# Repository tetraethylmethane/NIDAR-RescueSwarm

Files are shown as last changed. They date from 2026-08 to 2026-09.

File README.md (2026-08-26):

<h1 align="center">NIDAR RescueSwarm</h1>

<p align="center">
  Three autonomous drones that search a flood zone, find survivors, geotag them,<br>
  and drop medical kits — with no network, no pilot, and one operator who only presses start.
</p>

<p align="center">
  <b>NIDAR 2026–27 · Track 1 · Mission 1</b><br>
  <sub>MeitY · Drone Federation of India · SwaYaan</sub>
</p>

<p align="center">
  
  
  
  
</p>

---

## 1. Status

**Phase 0/1.** Sized end to end, requirements baselined against the rulebook, and the ground station runs as a system against three real ArduCopter SITL autopilots.

**What exists:** coverage planner, geotag geometry and its error model, ArduPilot parameter sets, safety-link protocol, ground station. All tested — 129 + 17 + 67 tests, 13 committed model outputs.

**What does not:** the aircraft, and the detector. There is **no camera anywhere in the loop**; survivors have only ever come from a simulator. Nothing has flown on hardware.

<p align="center">
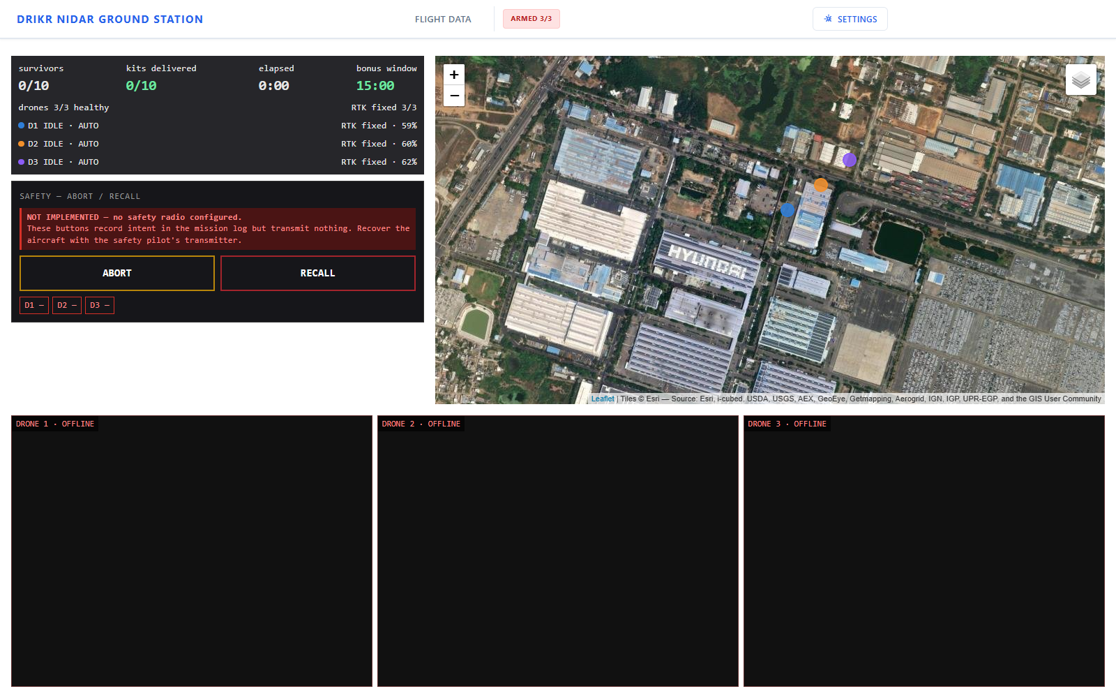
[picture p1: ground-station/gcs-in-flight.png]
Ground station mid-mission: three drones in AUTO at 40 m over offline satellite imagery
  
  <br>
  <sub>Three real autopilots flying the coverage planner's output in AUTO, in 6 m/s wind, over locally cached imagery. Every number came from an autopilot.<br>
  ▶ <a href="ground-station/mission-flight.mp4">mission-flight.mp4</a> · <a href="ground-station/README.md">ground-station/README.md</a></sub>
</p>

### Next actions

| # | Action | When | Why first |
|:--|:--|:--|:--|
| 1 | [Send the organiser questions](docs/requirements/organiser-questions.md) — drafted | This week | External latency; nothing else here has any |
| 2 | Start collecting recall data | P1 | The long pole. 250 points, irreducible calendar cost |
| 3 | Bench the cold-boot timing | P1 | The only constraint under 20 % margin, still modelled |

Registration Aug 2026 · reviews Oct and Dec · **finals Jan 2027**. About 21 weeks, but monsoon and exams cut the **flight-test window to ~8 weeks**. See the [development plan](docs/development-plan.md).

---

## 2. Design point

Outputs of a closed model in [`tools/sizing-model/`](tools/sizing-model/), reconciled with the BOM to ~2 %.

| Aircraft | | Mission | |
|:--|:--|:--|:--|
| Configuration | Quadrotor · 18 in CF folding props | Design mission | **7.7 min** of 30 |
| Battery | 6S3P 21700 · 18 cells · 292 Wh | Search | 60 m AGL at 8 m/s |
| MTOW | 6.36 kg *(model)* · 6.23 kg *(BOM)* | Sweep | 93 s/drone, 10 ha over 3 |
| **Fleet** | **19.1 kg** of 25 kg — 24 % margin | GSD | 1.82 cm/px — a person is ~93 px |
| Hover | 913 W · 9.7 kg/m² disk loading | Link | ≥13 dB at 600 m · 2.5 Mbps |
| Endurance | 15.3 min — **≈2.0× the mission** ⚠ | Geotag target | CEP50 ≤ 0.75 m with RTK |
| Thrust-to-weight | 2.0 static · hover at 50 % | Delivery target | ≥60 % within 2 m, ≥30 % within 1 m |

> ⚠ **The reserve is spent.** The 300 g parachute (SYS-41) takes endurance to ≈2.0× against a self-imposed ≥2.0× policy. Any further mass growth breaks it. See [`bom_reconcile.py`](tools/sizing-model/bom_reconcile.py).
>
> **Under review:** 40 m beats 60 m — 140 px on a person instead of 93, for 2.5 min of a 15 min allowance. Pending recall measurement in P7.

---

## 3. Proof

Three ArduCopter SITL instances, the real `rescueswarm-drone{1,2,3}.parm`, the real planned missions. Every number below came off MAVLink. Telemetry is committed in [`simulations/recordings/`](simulations/recordings/); the figures redraw from it.

### 3.1 The battery failsafe brings them home

`BATT_FS_LOW_ACT = 2` had been reviewed and unit-tested for weeks, and **no simulation ever loaded the file** — every SITL script used stock defaults, where the value is `0` and a low battery does nothing at all. Now proven end to end: RTL fires at **10 809 mAh of a 10 800 mAh trip**, on all three aircraft, within two seconds of each other.

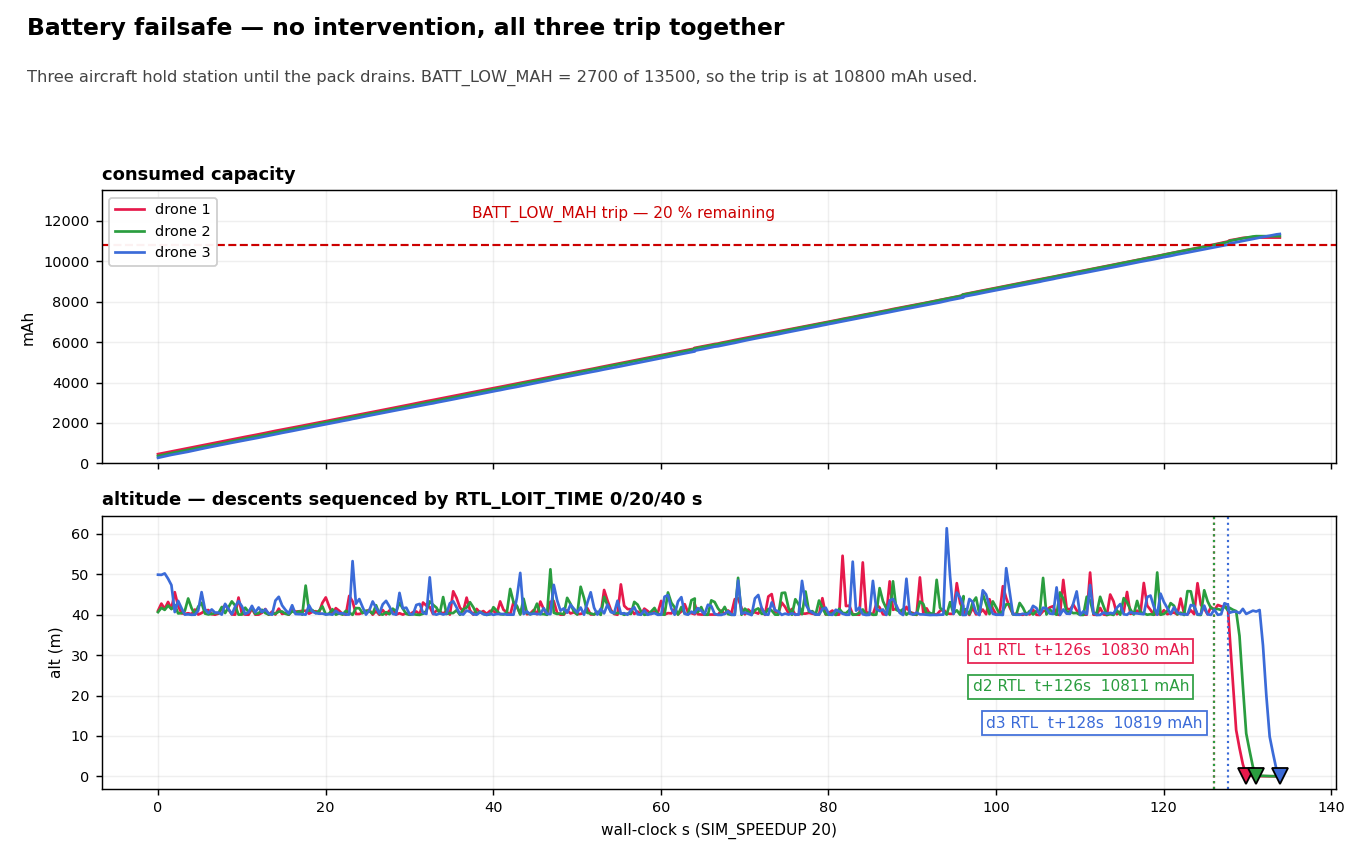
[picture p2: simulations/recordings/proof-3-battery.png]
Battery failsafe


### 3.2 They no longer collide

Three defects, none visible in review, all found by running the real artifact:

- **Launches were simultaneous.** Three aircraft leaving slots 1.22 m apart measured 1.3 m from each other at 2–3 m altitude. Now `NAV_DELAY` 0/15/30 s in the mission file.
- **Two of three swept the wrong way round**, finishing 516 m and 540 m from the pad on the lowest state of charge of the flight, because sweep direction keyed on drone index. Now all three finish inside 130 m, same path length.
- **They landed on top of each other.** See §4.

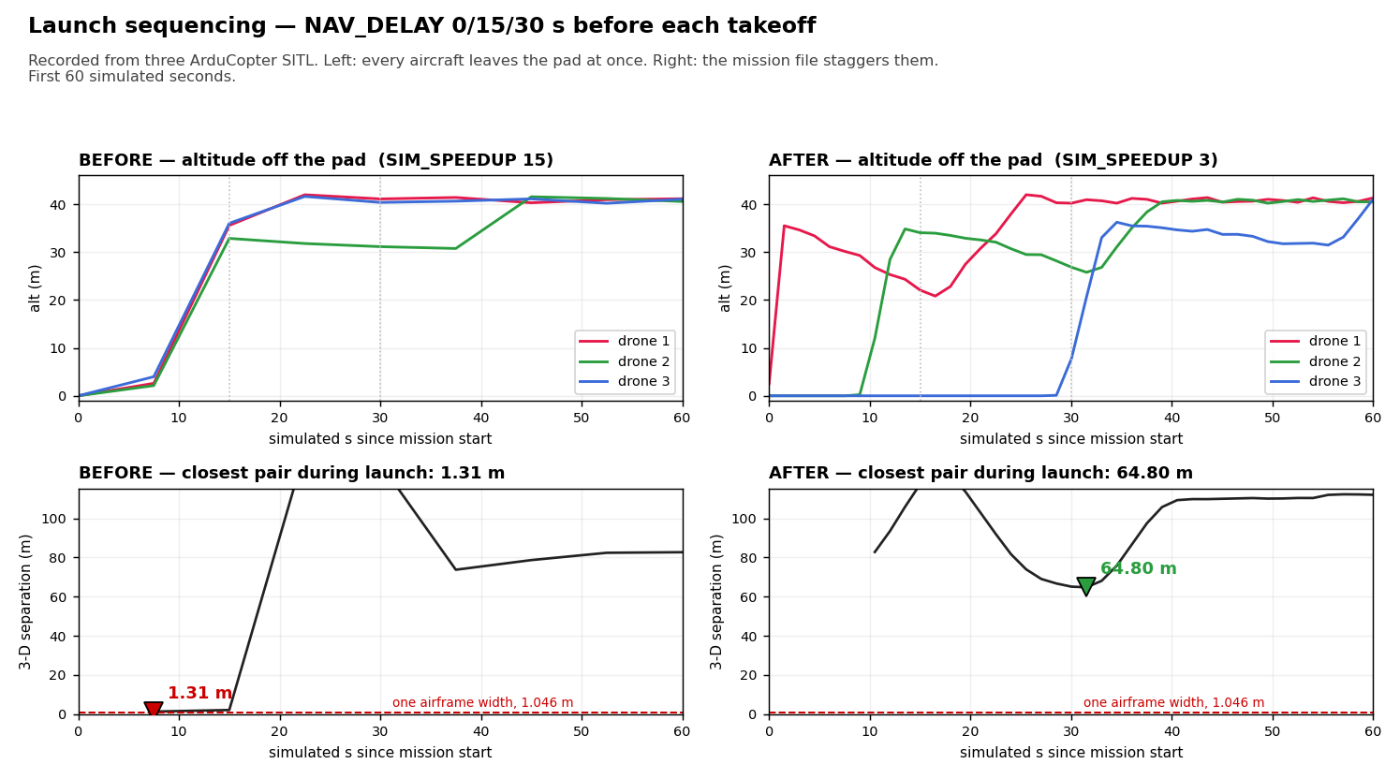
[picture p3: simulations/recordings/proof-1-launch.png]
Launch sequencing


| Separation, three aircraft | Before | After |
|:--|--:|--:|
| Launch, closest pair | 1.31 m | **64.80 m** |
| Whole flight, both airborne | 3.99 m | **5.51 m** |
| Closest horizontal, any time | 0.83 m — *overlap* | **1.89 m** |
| Recovery run, closest at any time | 0.83 m — *overlap* | **2.27 m** |

### 3.3 The search pattern

Each strip is swept twice, the second pass on the reverse heading, and every sweep finishes near the pad.

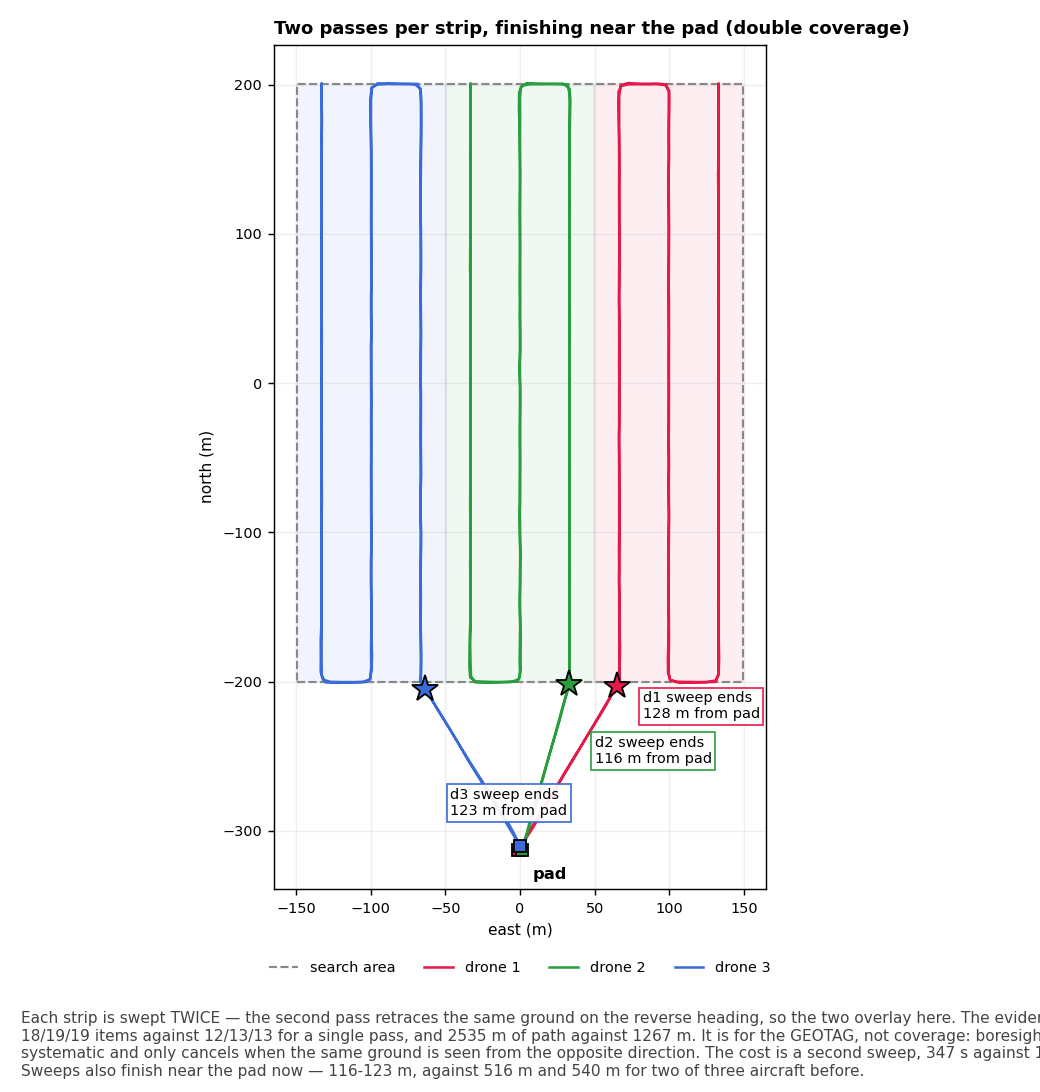
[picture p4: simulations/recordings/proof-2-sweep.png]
Sweep pattern


### 3.4 The pad

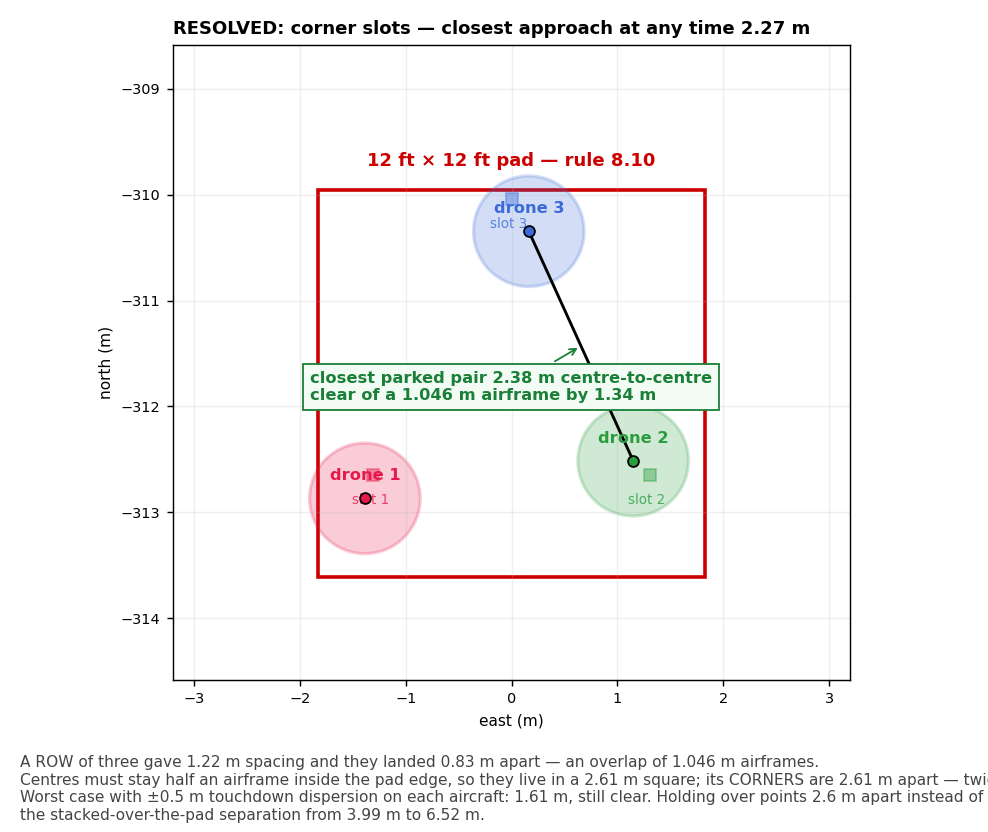
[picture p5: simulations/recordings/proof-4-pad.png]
Pad layout


> **"Measured" means measured in simulation.** That rules out whole classes of error and none of the physical ones. [HANDOFF.md](HANDOFF.md) §2 keeps measured, modelled and assumed apart.

---

## 4. Decisions

| Decision | Outcome | Why |
|:--|:--|:--|
| Coaxial X8? | **Rejected** | +59–119 % hover power, +34–50 % fleet mass, cuts the margin to 2 %, buys no footprint back, worst attitude bandwidth tested |
| Rotor count | **Quad** | Hex/octo match or beat it on physics, but cost 1.5–2× the propulsion integration on a 21-week calendar. Decided on schedule risk, not physics |
| Prop diameter | **18 in** | Matches the BOM, and better than 20 in on descent (0.42 v_i) and gust sensitivity (0.168) |
| Thrust-to-weight | **2.0** | Tilt only reaches 12° at 15 m/s — attitude authority is never the wind limit |
| Recovery chute | **Fit one** | Cannot meet the "land on the pad" condition, but −10 beats −50, so it is worth ~40 points anyway |
| Pad layout | **Corners, not a row** | A row is the worst packing on a square. Compliance said "3 per row"; they landed **0.83 m** apart — an overlap. Corners give 2.61 m instead of 1.22 m. Measured closest approach **0.83 → 2.27 m** |
| Search pattern | **Two passes, second reversed** | Not for coverage — one pass has no gaps. Boresight bias is *systematic*, so flying the reverse heading cancels it where more frames cannot. Costs a full second sweep |
| Launch and recovery | **Sequenced in the mission file** | `NAV_DELAY` 0/15/30 s and `RTL_LOIT_TIME` 0/20/40 s — parameters, not companion code, because the failsafe RTL is a mode change inside the flight controller |
| Motor-out redundancy | **Open** | Only rotors keep the aircraft *flying and scoring*, and only rotors work in the 6 m delivery hover. Ties to rotor count |

Numbers in [configuration trade](docs/sizing/configuration-trade.md).

---

## 5. Scoring, and what reading it properly changed

**1000 points:** 600 flight · 200 design review · 200 business strategy.

| Flight — 600 | Points | | Penalty | Cost |
|:--|--:|:--|:--|--:|
| Detection + geotagging | **250** | 25 each, max 10 | Manual input or reset | −50 |
| Kit delivery accuracy | **200** | ≤1 m: 20 · ≤2 m: 14 · ≤3 m: 8 | Crash | −50 |
| Multi-drone collaboration | 50 | binary | Geofence breach | −20 |
| Single GCS interface | 50 | binary | Landing outside the box | −10/drone |
| Finish inside 15 min | 50 | binary | <sub>capped at 150</sub> | |

Three findings that moved the design more than any engineering analysis did:

- **Geolocation gates 450 of 600 points**, not 250. Kits are scored from the survivor, so a drop is never better than the tag it aimed at. RTK alone is worth 82 delivery points.
- **We were designing to the worst zone.** The old ≤3 m target scored 8 of 20 per drop; the old "90 % within 5 m" requirement sat outside every zone and would have scored nothing.
- **Speed is worth 50 points and is already won.** The bonus needs 15 min; we fly 7.7. Spend the surplus on recall — fly lower, take more looks.

Full breakdown in [rulebook compliance](docs/requirements/rulebook-compliance.md).

---

## 6. Open

| Risk | Detail | Status |
|:--|:--|:--|
| **Setup margin** | 15 s against a 5-minute rule — modelled, not measured | Recovered by SYS-42/43; bench in P1 |
| **VRS on every delivery** | 2.5 m/s descent sits at 0.48 v_i, on the vortex-ring boundary | Fix in the flight profile, not the airframe |
| **Wind cliff at 8 m/s** | Search groundspeed is 8 m/s, so at that windspeed we make no headway. Wind is natural and uncapped | Requirement: 10 m/s headway (SYS-37) |
| **Business strategy** | 200 points, barely started; sponsorship evidence cannot be produced in the final week | Start now |

Four questions are [drafted and unsent](docs/requirements/organiser-questions.md) — how "correctly geotagged" is verified, whether a canopy descent scores −10 or −50, whether motor-out tolerance is required, and whether the pad can be surveyed beforehand. The first decides whether ~1–2 m of absolute base error costs anything against 250 points. Answers already received are recorded in the same file.

---

## 7. Repository

```text
HANDOFF.md                  read this first if you are picking the project up
docs/                       requirements, sizing, business, system overview
tools/sizing-model/         the model everything traces back to
hardware/bom/               Indian BOM + indigenisation scorecard
autonomy/coverage_planner/  boundary in, one AUTO mission per drone out
perception/geotagging/      pixel to lat/lon, and a Monte Carlo of its error
firmware/ardupilot-params/  the five failsafes, as parameters not code
simulations/                SITL harness, committed telemetry, figures
ground-station/             mission_backend + the GCS engineering record
```

The **running** ground station — Flask server, React client, SITL launch scripts — is in [NIDAR-GSC](https://github.com/tetraethylmethane/NIDAR-GSC). What lives here is `ground-station/mission_backend/` (fleet model, KML parser, MAVLink ingest, and the SYS-20 module split that makes a retask route structurally unreachable), plus the requirement evidence: [PLAN.md](ground-station/PLAN.md), the flight screenshots and [mission-flight.mp4](ground-station/mission-flight.mp4).

> ⚠ **The two copies of `mission_backend` have drifted.** `mavlink_ingest.py` is 186 lines here against 304 in NIDAR-GSC, and only the GSC copy calls `SET_MESSAGE_INTERVAL` — without which a passive listener receives nothing but heartbeats. The GSC copy is the one that flies; this one is what CI tests. See [HANDOFF.md](HANDOFF.md) §4.

`communication/` is still planned.

```bash
pip install -r tools/sizing-model/requirements.txt
python3 tools/sizing-model/rescueswarm_sizing_model.py   # the design point
python3 tools/sizing-model/bom_reconcile.py              # read before ordering

export NIDAR_SYS=$PWD
../NIDAR-GSC/scripts/test-battery-failsafe.sh            # low battery brings it home
python3 simulations/sitl/fly_and_record.py               # three aircraft fly the plan
python3 simulations/sitl/proof_figures.py                # redraw §3 from telemetry
```

`NIDAR_SPEEDUP=3` slows the sim enough to see the launch stagger. Do **not** use `NIDAR-GSC/scripts/run-sim.sh` — it launches a fixed wing with no project parameters.

> **Change the model, re-run it, commit the new output in the same commit.** Every number in this README traces to [`docs/sizing/`](docs/sizing/), and CI fails if one drifts.

| Document | What's in it |
|:--|:--|
| [Handoff](HANDOFF.md) | **Start here.** What is proven, what waits on a human, and the traps that have cost days |
| [Competition day](docs/checklists/competition-day.md) | How the GCS is actually operated on the day — draft, never rehearsed |
| [System overview](docs/system-overview.md) | Mission flow, architecture, perception, indigenisation, failsafes |
| [Sizing calculations](docs/sizing/sizing-calculations.md) | Why every number is what it is |
| [Requirements baseline](docs/requirements/requirements-baseline.md) | Every SYS-xx requirement, traced to a rule and a verification method |
| [Rulebook compliance](docs/requirements/rulebook-compliance.md) | Rule-by-rule matrix, scoring, conflicts |
| [Development plan](docs/development-plan.md) | Schedule, critical path, risk and de-scope order |
| [Implementation plan](docs/implementation-plan.md) | What to build for autonomy, perception and failsafes — and what can be skipped |
| [Frame design constraints](docs/frame-design-constraints.md) | What CAD needs before the first part is cut |
| [Questions to lead](docs/questions-to-lead.md) | Internal blockers waiting on a decision — currently, which camera we are buying |

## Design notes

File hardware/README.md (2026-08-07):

# hardware

CAD, electronics, BOM, payload mechanism

**Status: not yet written.** Planned for the phase noted in
[`../docs/development-plan.md`](../docs/development-plan.md).

Requirements this directory must satisfy: SYS-03, SYS-16, SYS-18 — see
[`../docs/requirements/requirements-baseline.md`](../docs/requirements/requirements-baseline.md).

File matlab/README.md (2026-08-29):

# MATLAB analysis, verification and simulation

MATLAB is the primary tool for figures, verification and simulation. It is not
the source of truth for the design.

## The split, and why

| | |
|---|---|
| **Python** (`tools/sizing-model/`) | owns the **primitives** — the constants the design chooses |
| **MATLAB** (here) | **re-derives** from those primitives, **asserts** against Python's results, and does everything dynamic |

Nothing here retypes a design constant. Two copies of a constant is the defect
this repository keeps finding in itself: three different tile counts in one
document, a mass line naming a computer that was never bought, a fusion figure
computed at an altitude the design had abandoned. Two authorities always
diverge, and the divergence is silent.

## Pipeline

```
python matlab/export_model.py             # Python -> data/model.json
matlab -batch "cd matlab; run_all"          # verify + figures + simulations
matlab -batch "cd matlab; run_all('verify')"   # or one stage at a time
```

## What each part does

See CHECKLIST.md for the status of every figure, calculation, verification and
simulation.

## Layout

```
matlab/
  run_all.m          verify + figures + simulations, one entry point
  export_model.py    Python -> data/model.json
  lib/               rs_model, rs_style, rs_axes, rs_save
  calc/              (reserved)
  verify/            verify_model.m -- 28 independent cross-checks
  figures/           fig_detect, fig_looks, fig_energy
  sim/               sim_pack_sag
  data/              model.json and results
```

**`export_model.py`** writes `data/model.json`: 38 primitives, 34 derived values, the
mass statement and the mission profile.

**`verify_model.m`** is the cross-validation. The Python model asserts each
derivation against its own result, which catches an inconsistent edit but *not*
a mistake in the derivation itself — the same expression sits on both sides.
This re-derives all of it independently, in another language, from primitives
only. **28 checks, currently all passing** -- most to machine precision.

Two of those are deliberately redundant: pack energy is computed both from the
cell arithmetic (exact identity) and from mass times specific energy (agrees to
0.6 %). The loose tolerance on the second is the point — it says the specific
energy assumption is consistent with the cell count rather than tuned to it.

**`pack_sag.m`** is the dynamic simulation, and the one thing here that
produces information the static model cannot. Second-order Thevenin cell model
driven by the real mission profile.

## The result that matters

```
minimum pack voltage   17.05 V at t = 432 s
failsafe floor         18.00 V
margin                 -0.95 V
SOC at that moment     64 %
sag at the gust        5.82 V   (static model assumes 4.60)
```

The aircraft crosses its own low-voltage floor during a legitimate gust
recovery, at two-thirds charge, long before the 80 % DoD limit the reserve
policy is built around. Dynamic sag exceeds the static figure by 1.2 V because
the diffusion terms add to the instantaneous ohmic drop.

A failsafe set on instantaneous pack volts would command return-to-land
mid-search on a healthy pack.

**Caveat.** R0 is calibrated so the static sag matches the 4.6 V the proposal
assumes; R1/C1/R2/C2 are typical high-drain 21700 values, not P45B-specific. So
the shape is trustworthy and the magnitude inherits that assumption. P2 replaces
R0 with a measured DC-IR, and that is when this becomes evidence rather than
analysis.

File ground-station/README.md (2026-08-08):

# ground-station

The **Drikr NIDAR Ground Station** — mission view, telemetry, video, abort.

Code lives in [`tetraethylmethane/NIDAR-GSC`](https://github.com/tetraethylmethane/NIDAR-GSC);
this directory holds the engineering record. Mission-build rules that must not be
undone are in [`MISSION.md`](https://github.com/tetraethylmethane/NIDAR-GSC/blob/main/MISSION.md).

Requirements: **SYS-20, SYS-23, SYS-25, SYS-26, SYS-27** — see
[`../docs/requirements/requirements-baseline.md`](../docs/requirements/requirements-baseline.md).

```bash
cd server && python -m pytest mission_tests -q      # 118 tests
python utils/slippy_map_getter.py --verify          # offline tiles intact
cd ../client && CI=true npx react-scripts test --watchAll=false   # 22 render tests
cd .. && ./scripts/check-no-network.sh              # rule 8.4 guard
node scripts/browser_check.js                       # the page, in real Chromium
```

---

## Status

| Requirement | State |
|---|---|
| No external network (SYS-23, rule 8.4) | ✅ Poller removed, CI-guarded · tiles render offline |
| No mission-altering commands (SYS-20, rule 8.16) | ✅ Legacy blueprint **not registered**; dev UI not rendered |
| Single unified interface, 3 drones (SYS-25, rule 8.13) | ✅ Verified against **three real ArduCopter autopilots** |
| All eight rule 8.14 displays (SYS-26) | ✅ Rendered and asserted in a real browser |
| Three video feeds (SYS-27, rule 8.14) | ✅ **Live H.264 over WebRTC**, end to end |
| Abort and recall (rule 8.19) | ✅ Acknowledged end to end · ⚠ **no 868 MHz radio yet** |

**118 server tests · 22 render tests · a browser check · CI on all of it.**

---

## The server had never actually started

That was the headline defect, and it was hidden by a test.

`app.py` → `apps.uav` → `handlers/uav.py` → `dronekit`, and DroneKit does
`collections.MutableMapping`, which moved to `collections.abc` in **Python
3.10**. The mission server could not boot on any current interpreter. The smoke
test had been installing a fake `dronekit` module to get around it — so the
suite passed on 3.12 while the program did not run on 3.12. A green tick over a
server nobody could start.

The fix was not to pin Python 3.9. **In a mission build the legacy `UAVHandler`
is redundant**: `mavlink_ingest.py` already carries position, mode, battery and
GNSS fix for all three aircraft over pymavlink, which DroneKit cannot do at all,
being single-vehicle by construction. Mission mode no longer imports
`apps.uav`, `apps.image` or `groundstation`, so DroneKit is **absent from the
process** rather than merely unused, and `app.gs` is `None`.

Nothing is stubbed in the smoke test any more, and it asserts
`"dronekit" not in sys.modules` directly. Absence is a fact about the running
process; "we do not call it" is only a claim about intent.

It settles SYS-20 more strongly too. The legacy blueprint's 31 routes — including
`/uav/commands/insert` and `/uav/commands/jump`, each a −50 under rule 8.16 —
are no longer in the URL map at all. Refusing a command is good; not having one
is better. The 403 guard stays as defence in depth, matching on path prefix so a
legacy path answers *"blocked in mission mode"* rather than a bare 404, which
would read as "wrong path, try another one".

Running it, for the first time:

```
GET  /                    200  Ground Station Backend
GET  /api/fleet           200  {"mission_mode":true,"phases":{"1":"IDLE",...
GET  /api/safety/status   200  {"state":"NO_RADIO","configured":false,...
POST /uav/arm             403  Blocked in mission mode
POST /uav/commands/insert 403  Blocked in mission mode
POST /api/safety/abort    503  state=NO_RADIO configured=False
dronekit in sys.modules : False        app.gs : None        python : 3.12.4
```

> **Known limitation, recorded not hidden.** The **dev** build
> (`MISSION_MODE=0`) still needs DroneKit and Python 3.9 —
> `mission_backend/dev_commands.py` is a route stub that acknowledges commands
> without sending them. Tolerable: the dev build is not the scored artefact and
> QGroundControl does bring-up better. `app.py` catches the import failure and
> prints the three options instead of a traceback about `MutableMapping`.

---

## The tile cache would have failed silently

`client/public/map` was empty, so with the network down the map is **blank** —
no boundary, no survivors, no aircraft. `slippy_map_getter.py` exists to prevent
that, and it had a defect that would only ever have surfaced on mission day.

**It wrote the response body to a `.png` without ever looking at it.** A 404
page, a rate-limit body or a truncated response landed on disk as a plausible
tile, and because the resume check was `os.path.isfile`, it was then skipped
forever. The cache would report complete, error never, and render grey squares
during a scored mission.

Every tile is now validated by magic number before it is written, written via a
temp file and rename so an interrupted run cannot leave a half-tile the resume
check trusts, and `--verify` re-checks what is already cached. **An empty cache
directory now fails verification** — the directory is created by the download
itself, so "it exists" proved nothing.

One trap found only by running it against the real server: **ArcGIS answers a
`.png` request with JPEG data.** Validating a PNG signature specifically — the
obvious way to write the check — rejects every real tile and caches nothing at
all, which is a worse failure than the original because it is total and silent.
The first version of this fix did exactly that, and downloaded 0 of 4 tiles.

It also no longer asks three interactive questions (so it can run from a script)
and no longer defaults to 38.14, −76.42, a field in Maryland left over from
AUVSI. `--dry-run` and `--verify` do not import `requests`, because needing an
HTTP library to check that *offline* tiles are intact would be a poor joke.

```bash
cd server
python utils/slippy_map_getter.py --center LAT,LON --radius-km 10 --zoom 10-18 --dry-run
python utils/slippy_map_getter.py --center LAT,LON --radius-km 10 --zoom 10-16 --yes
python utils/slippy_map_getter.py --verify
```

The dry run exists because **zoom 18 is most of the download**. Over a 10 km
radius, zoom 10–16 is ~1,700 tiles (~41 MB); adding 17 and 18 takes it to
~24,700 tiles (~600 MB) and roughly 50 minutes. Run it **weeks ahead** — the
mission area is not known until the KML arrives during setup, and there is no
network at the venue to fetch tiles with once you know where you are.

---

## The dev UI no longer renders in a mission build

`Servo`, `FlightPlanToolbar`, `Main` and the `Params` page still shipped. The
server refused them, so no rule was broken — that is not the argument. **A
control that silently does nothing is its own hazard:** under pressure someone
clicks *Write To*, sees no error, and believes the aircraft took it. The same
reasoning removed waypoint insertion from the map.

In a mission build the left column is **mission status and abort, and nothing
else**. `Params` refuses to render and says why, because `/params` is a URL and
browsers remember URLs. The legacy `/uav/quick` poll is switched off rather than
left hitting a dead path twice a second for eight minutes.

The client learns the mode from `mission_mode` on the `/api/fleet` snapshot, and
it defaults to **true** in every path — before the first poll returns, after the
backend goes away, and when the field is missing. Only an explicit `false`
unlocks anything.

Fixing this surfaced a latent bug in `useInterval`: it had no way to express
"not now", and `setInterval(fn, null)` coerces the delay to 0, which is a busy
loop rather than a stopped one. It also pinned the first render's closure
forever behind an empty dependency array, so a callback reading state saw its
initial value for the life of the component while looking perfectly correct.
Both fixed; every existing caller passes a constant delay and is unaffected.

---

## The components now actually render

Everything in `client/src/mission` had been written, compiled and shipped
**without a single component ever being mounted.** That is how two rule 8.14
displays came to be "built" while being referenced by zero files. A build proves
the syntax is valid; it proves nothing reaches a screen.

`@testing-library/react` was already in `devDependencies` and entirely unused.
**16 tests now mount `MissionStatus` and `AbortPanel` and read the resulting
DOM** — rule 8.14 items 1, 4, 6, 7 and 8 asserted as *visible text*, because a
jury looks at a screen, not at a JSON payload. Also covered: a non-RTK survivor
tag raises a visible warning; a stale display announces itself; the empty fleet
renders, which is the state at T-0 before the first MAVLink packet arrives, and
where a crash would mean a blank screen as the mission starts.

For abort specifically: no-radio reads *NOT IMPLEMENTED* rather than OK,
per-aircraft acknowledgement is displayed, and one click arms while transmitting
nothing — only the second click fires. Two-step confirm is easy to write and
easy to break; a refactor that hoists the fetch out of the confirm branch looks
harmless and turns a misclick during a nominal mission into an abort.

Writing these caught two mistakes in the *fixtures* rather than the code: a
delivery state that is not in `fleet.py`'s ladder, which would have passed
silently through a `|| state` fallback, and assertions using `getByText` where
two elements legitimately match.

**CI now runs all of it.** Nothing did before —
[`mission-build.yml`](https://github.com/tetraethylmethane/NIDAR-GSC/blob/main/.github/workflows/mission-build.yml)
runs the 107 server tests, the SYS-20 route check, `check-no-network.sh`, the
render tests and the client build, on **Python 3.12 with nothing stubbed**. It
asserts DroneKit is absent, `app.gs` is `None` and no `/uav` route exists.
Verified to *fail*: with the legacy blueprint re-registered, DroneKit reinserted
and `GroundStation` reconstructed, all three assertions trip. A guard that cannot
fail is not a guard.

---

## The coverage plan has been flown

```
coverage planner -> QGC WPL 110 -> 3 x ArduCopter SITL in AUTO -> the GCS
```

Three real ArduPilot autopilots flew the planner's own output, in wind, and
completed it:

| | result |
|---|---|
| drone 1 | **COMPLETED** — wp 9/9, max alt 40.1 m, landed on its pad |
| drone 2 | **COMPLETED** — wp 9/9, max alt 40.2 m, landed on its pad |
| drone 3 | **COMPLETED** — wp 9/9, max alt 40.1 m, landed on its pad |

6 m/s wind, turbulence 3. Nothing in the flown path was hand-written — it is
`mission.py`'s `QGC WPL 110` output, uploaded over `MISSION_ITEM_INT` (the int
variant deliberately: `MISSION_ITEM` uses float32 for latitude and quantises to
1–2 m, and the whole delivery budget is 1 m zones).

Run it with [`scripts/sim-flight.sh`](https://github.com/tetraethylmethane/NIDAR-GSC/blob/main/scripts/sim-flight.sh).

### The operator's screen, mid-flight

the ground station during the flight

`ARMED 3/3` in red, all three in AUTO, RTK fixed, batteries drawing down
59/60/62 %, three markers separated across their own search strips on offline
imagery. Every number on that screen came from an autopilot.

The whole mission is recorded in [`mission-flight.mp4`](mission-flight.mp4) —
600 frames over five real-time minutes, captured by
[`scripts/record_mission.js`](https://github.com/tetraethylmethane/NIDAR-GSC/blob/main/scripts/record_mission.js),
which also writes a fleet data track alongside the frames so the clip can be
read rather than squinted at:

```
t+  1s  alt 40/40/40   AUTO/AUTO/AUTO      cruise
t+301s  alt 11/19/29   AUTO/AUTO/AUTO      recovering, staggered
t+323s  alt  0/ 2/ 6
t+338s  alt  0/ 0/ 0                       all three down
```

It is a test as well as a demo. Anything that only fails over time — a leaking
poll, a marker that stops updating, a feed that drops after ninety seconds — is
invisible to a screenshot and obvious in five minutes of frames. Three console
errors across the whole run, all from the backend being shut down at the end.

### It took seven attempts, and one of them is worth reading

Three runs were diagnosed from readings of *"alt 0.00 m, throttle 0 %, no RC"*.
None of those were measurements. The flight harness was a **passive listener**
on its private MAVLink link, so ArduPilot sent it heartbeats and nothing else,
and every variable sat at its initialised `0.0`.

That is exactly the defect found in the ground station's own ingest earlier the
same day — reproduced in the harness written to watch for it. The GCS, which
*does* request streams, was reporting the same aircraft at 40 m at the time.

**Absent data is not zero data.** Two confident wrong diagnoses were built on
that confusion, including one about RC failsafe, before `SET_MESSAGE_INTERVAL`
was added to the harness too.

The other six taught smaller lessons, all of the same shape: arming is a
request that can be *refused* (checking the ACK surfaced *"Gyros inconsistent"*
and *"AHRS: waiting for home"*); switching to AUTO does not start a mission and
`MISSION_START` returns `ACCEPTED` without starting one either; `DISARM_DELAY`
disarms the first aircraft while the third is still passing pre-arm; and
completion is *landed and disarmed*, not a mode change, because the mission
ends with RTL as an **item** so the mode stays AUTO throughout.

---

## Gazebo: the perception loop finally has pixels

SITL gives real dynamics, a real EKF and real failsafe logic, but it **renders
nothing** — so detection → geotag → mission-state → GCS had only ever been fed
by `sim_mission.py`. Gazebo Harmonic plus `ardupilot_gazebo` closes that.

Verified: headless Gazebo, ArduPilot plugin on UDP 9002, SITL **armed and
climbing under Gazebo physics**, and **65 PNG frames at 640×480** written from
the aircraft's own camera.

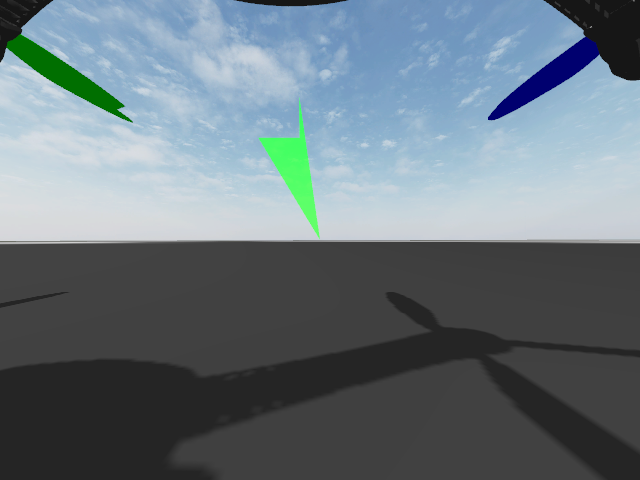
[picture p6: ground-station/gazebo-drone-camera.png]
a frame from the drone's camera in Gazebo


<sub>An actual rendered frame — the aircraft's rotors and its shadow on the
ground. The gimbal ships pointing at the horizon, which is useless for finding
someone in water; <a href="https://github.com/tetraethylmethane/NIDAR-GSC/blob/main/scripts/gz-flight.sh"><code>gz-flight.sh</code></a>
commands it to nadir.</sub>

**Three things cost real time, all now handled by the script:**

1. **`gazebo-iris.parm`, not `copter.parm`.** With the generic defaults the JSON
   physics link never completes — SITL logs *"No JSON sensor message received,
   resending servos"* forever, the EKF never gets an IMU, and arming is refused
   with *"Need Position Estimate"*. Swapping the defaults file fixed it outright.
2. **Lockstep makes real-time factor meaningless as a health metric.** The
   plugin sets `<lock_step>1</lock_step>`, so Gazebo advances only when SITL
   sends servos. RTF ≈ 0.3 is *expected and harmless*. I initially blamed RTF
   0.31 for the arming failure and was wrong — cause (1) was the real one.
   Budget wall-clock waits at ~3×.
3. **The gimbal looks at the horizon by default.** NIDAR searches nadir at 40 m.

Worth stating once: use this for **plumbing** — does a detection become a
geotag, does it reach the GCS, does the chain hold for eight minutes. **Not for
recall.** Synthetic scenery flatters a detector and recall is worth 250 points;
measure that on real flood imagery and real dummies.

> GPU note: WSL exposes the GPU as `root:render`, and Ubuntu puts you in
> `video` but not `render`. Without `usermod -aG render` Gazebo falls back to
> software rendering. That is slow but, because of lockstep, **not** what stops
> the aircraft arming.

---

## It has now run as a system

Client, backend, **three real ArduCopter autopilots**, the mission-state feed,
the offline tile cache and MediaMTX, all at once, with a browser looking at the
result. ArduPilot SITL built from source in WSL; the prebuilt Windows binaries
are Cygwin builds that Defender blocks, and working around someone's antivirus
is not the move.

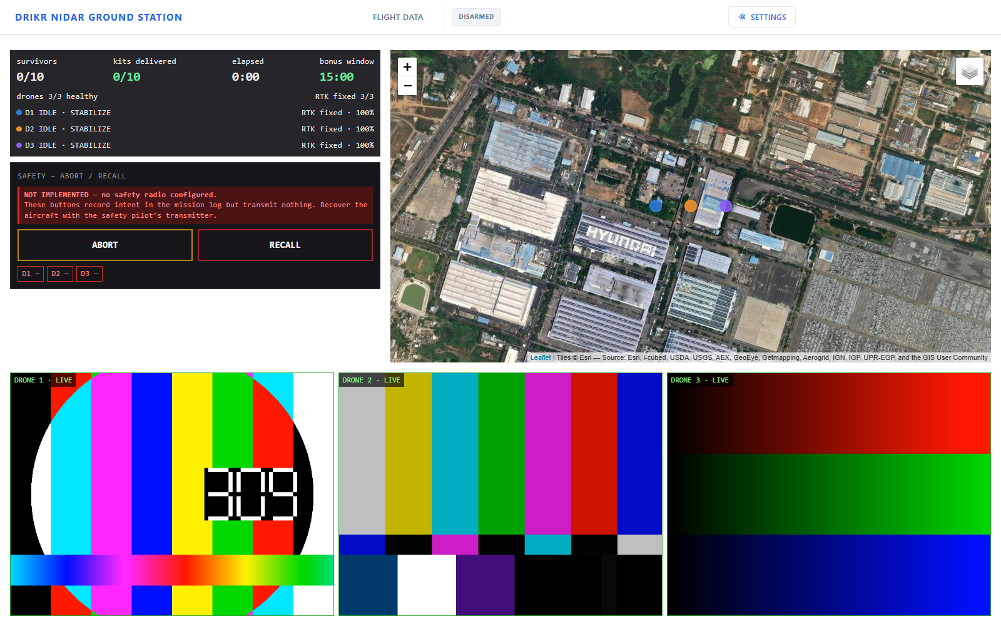
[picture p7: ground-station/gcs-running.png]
the ground station running against three SITL aircraft


Offline satellite imagery from the local cache, three drone markers at their
distinct SITL positions, three H.264 feeds live over WebRTC, `DISARMED` correct
in the header, abort honestly reporting no radio. Zero HTTP errors, zero console
errors, zero failed requests.

Doing it found **eight defects**, none of which any existing test could have
caught.

### The big one: we were receiving almost no telemetry

ArduPilot streams at the rates set by the `SRx_*` parameters **for the channel
the GCS is on**, and a channel that has never had a stream request sends almost
nothing. Measured:

| What the GCS does | What arrives |
|---|---|
| Listen passively — **what the code did** | `HEARTBEAT` only, 1 Hz |
| + GCS heartbeat | still `HEARTBEAT` only |
| + `SET_MESSAGE_INTERVAL` | everything, at the rates asked for |

So the fleet populated with flight mode and armed state and **nothing else** —
`lat`, `lon`, `alt`, `battery_pct`, `gnss_fix` all `null`. Rule 8.14 items 3 and
4 blank for the whole mission, and the survivor fix quality unknown.

The existing tests call `handle_message()` with constructed messages. That
verifies the mapping and says nothing about whether the messages arrive.
*"We decode `GLOBAL_POSITION_INT` correctly"* and *"we receive
`GLOBAL_POSITION_INT`"* are different claims, and only a real autopilot can tell
them apart.

### The other seven

**MediaMTX had never started.** `hlsDisable`/`rtmpDisable`/`srtDisable` is the
pre-1.x spelling; MediaMTX rejects unknown fields and exits without opening a
port. Running it also caught **MoQ** — new in v1.20, on by default — quietly
opening a QUIC server and minting a TLS certificate.

**The backend URL was hardcoded** to `172.29.93.93`, a machine on the previous
team's network. Nothing could reach a backend anywhere else without editing
source and rebuilding, which is much of why client and server had never met.

**The arm badge said ARMED when nothing was armed.** `App.js` renders
`<Header />` with no props, `Aarmed` defaulted to `""`, and
`"".includes("DISARMED")` is `false` — so it showed a green ARMED with three
disarmed aircraft, and with the backend switched off. Now `NO DATA` /
`DISARMED` / `ARMED n/3`, and ARMED is no longer styled the same green as
"healthy". Armed means the propellers can spin.

**A missing route returned 500, not 404**, because the catch-all error handler
swallowed werkzeug's `HTTPException`. A 500 says the ground station is broken.

**`ref` on `MapContainer` does nothing in react-leaflet 3.2.5** — that version
uses `whenCreated`. The existing `createRef()` was a dead ref.

**The map never followed the aircraft.** It opened on a hardcoded Delhi
coordinate and stayed there — which, with tiles cached for the operating area,
renders as a grey rectangle with the boundary drawn on nothing: *the exact
appearance of a broken tile cache, produced by a completely healthy one.*

**The map polled a dev route on every mount** (`/uav/commands/export`), which is
what produced the 500.

### The abort path has now been exercised

`sim_radio.py` binds the port the GCS transmits to and decodes each frame with
the real `safety_link.protocol.Receiver` — the actual aircraft-side class, not a
mock:

| Scenario | Result |
|---|---|
| all three acknowledge | `ACKNOWLEDGED` in <1 s, 3 frames, then transmission stops |
| `--deaf 2` | `acked=[1,3] missing=[2]` held visible, `TIMEOUT` at 10 s |
| `--loss 0.5` | repeats still get all three through |

The `--deaf` case is the one worth having — it is exactly what the panel exists
to surface.

---

## What is still not done

- **The safety radio itself.** `sim_radio.py` proves the framing, sequencing,
  dedup, addressing and acknowledgement. It proves **nothing about 868 MHz** —
  not range, airtime, the LoRa module, interference or the aerial.
- **No tiles are cached for the venue.** The tooling is fixed and 681 tiles were
  cached for the test area to prove the path, but the real coordinates are not
  known and this must be run weeks ahead.
- **No real aircraft.** SITL is a genuine ArduPilot autopilot flying the real
  plan in simulated wind, but it has no radio link, no companion computer, no
  mesh, no camera and no airframe.
- **The camera exists but nothing consumes it yet.** Gazebo now renders a
  downward camera from a flying aircraft (see below), so the pixels are there —
  but `perception/` is still empty, so nothing detects, geotags or publishes
  from them.
- **The measured video bitrate means nothing.** Synthetic test patterns are
  nearly static and compress to almost nothing; the 0.9 Mbps per feed in the RF
  budget is untested against real flood imagery.

Everything on that list needs hardware or a venue. **Nothing is left that can be
done at a desk** — which was not true this morning, when the list was DroneKit,
tiles, dev-UI gating, render tests, CI, SITL, MediaMTX and a browser.

The remaining ground-station work is P7–P9 field validation: attach the radio,
fly the aircraft, cache the venue, and run the pre-competition checklist with
the interfaces physically down.

---

## How it works

**Two ingest paths, deliberately separate.** MAVLink via mavlink-router carries
position, mode, battery and GNSS fix. A 5 Hz JSON document over the mesh carries
region, task, detections and deliveries — MAVLink has no message for *"survivor
at lat/lon, confidence 0.91, confirmed over 7 frames, RTK-fixed"*, and bending
`NAMED_VALUE_FLOAT` into that shape is a trap.

**Mission mode is structural, not a flag.** `MISSION_MODE=1` (the default, so the
safe build is the default) never imports the command blueprint, and refuses every
state-changing method on the legacy `/uav` routes. A flag can be flipped by a
config file; an unimported module cannot be reached.

**Survivor dedup prefers fix quality over recency.** Two aircraft can see the same
survivor, and a later `RTK_FLOAT` tag is metres worse than an earlier
`RTK_FIXED` one. Ranking is fix → frames → confidence; confidence is last because
it is worth nothing in position terms.

**Abort is the secondary path.** The primary is `RC7_OPTION=4` driving the flight
controller directly, which survives a hung companion — and a hung companion is a
reason to abort. This layer adds addressing, acknowledgement and an audit trail.

---

## Verified without hardware

`sim_mission.py` flies three synthetic drones including the awkward cases — a
drone dropping off the mesh, a survivor re-tagged with a better fix by a
different aircraft, and a tag taken without RTK. Against a real `Fleet` and a
real socket:

```
datagrams accepted : 5287      rejected : 0
survivors found    : 6         kits delivered : 6
survivor 3 fix     : RTK_FIXED (drone 3)   ← dedup preferred fix over recency
warnings           : survivor 6 tagged without RTK (3D)
```

Both safety guards were verified to **fail** when the fault is reintroduced: a
command route forced into the mission build fails three tests, and a restored
ArcGIS URL fails the network check. A guard that cannot fail is not a guard.

---

## History

The inherited codebase and the three blockers it shipped with are archived in
[`../docs/gcs-inherited-review.md`](../docs/gcs-inherited-review.md). Worth
reading before adopting any other codebase written for a different competition.

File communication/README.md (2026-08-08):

# communication

batman-adv mesh, mavlink-router, and the 868 MHz safety link.

## Built

### `safety_link/` — abort and recall

The wire format that makes `/api/safety/abort` real. Built to the three
constraints in [`../docs/implementation-plan.md`](../docs/implementation-plan.md) §4:

1. **Off the mesh.** The reason to abort is often that the mesh failed, so this
   runs on the separate 865-867 MHz radio.
2. **Framed, sequenced, acknowledged per aircraft.** LoRa is lossy; a single
   unacknowledged packet is a hope, not a command. The operator sees *which*
   aircraft accepted - "abort sent" and "abort received" are different claims.
3. **Secondary to a hardware path.** The primary abort is the safety receiver
   driving `RC7_OPTION=4` (RTL) straight into the flight controller, which works
   with a hung companion. This layer adds addressing and an audit trail.

12-byte CRC-16/CCITT frames, ~60 ms of airtime at SF7. Tested against single-bit
flips at 14 positions, truncation, replay, stale frames, partial acknowledgement,
and a full exchange with **60 % packet loss in both directions** - where the
abort still reaches all three aircraft.

> The GCS endpoint still sets a flag that nothing reads. This is the wire
> format, not the wiring. The UI must keep saying **NOT IMPLEMENTED** until the
> radio is connected.

## Not built

`mesh/` (batman-adv config and link monitoring) and `mavlink-router/` config.

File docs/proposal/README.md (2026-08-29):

# Funding proposal

`rescueswarm-proposal.tex` — IEEEtran conference format, **9 pages, 6 figures**.

## Figures

| Fig. | Content | Source |
|---|---|---|
| 1 | System architecture | TikZ, drawn in the document |
| 2 | Autonomous mission sequence | TikZ, drawn in the document |
| 3 | Launch deconfliction, before/after | [`proof-1-launch.png`](../../simulations/recordings/) |
| 4 | Recovery pad slot geometry | [`proof-4-pad.png`](../../simulations/recordings/) |
| 5 | Coverage decomposition and return geometry | [`proof-2-sweep.png`](../../simulations/recordings/) |
| 6 | Ground control station | [`gcs-running.png`](../../ground-station/) |

Figures 3–6 are committed simulation output, referenced in place via
`\graphicspath` rather than duplicated into this directory. Figure 6 is used
**uncropped**, including the panel showing that abort/recall is not yet wired to
a safety radio; the proposal states this in §VI-C rather than hiding it.

## Building

```sh
cd docs/proposal
pdflatex rescueswarm-proposal.tex
pdflatex rescueswarm-proposal.tex   # second pass resolves cross-references
```

Compiles clean: **0 errors, 0 overfull boxes, 7 pages.** Build artefacts
(`.pdf`, `.aux`, `.log`, `.out`) are gitignored and regenerate from the source,
the same convention the simulation GIFs use.

**Dependencies.** `IEEEtran`, `amsmath`, `amssymb`, `graphicx`, `booktabs`,
`array`, `url`, `hyperref`. On a minimal MiKTeX install, `mpm --update-db`
followed by `mpm --require=<pkg>` resolves them; `hyperref` pulls a long
dependency chain. `cite` and `balance` are deliberately **not** required — both
are optional conveniences, and omitting them keeps the document compilable on a
stock installation.

## Before sending it anywhere

Two `TODO` markers are live in the source:

| Location | What is needed |
|---|---|
| `\author{...}` | Names, department, institution, city, emails |
| `\section*{Acknowledgment}` | Institutional support, mentors, suppliers who provided evaluation hardware |

## Cost options: corrected on review, 2026-08-12

The first cost pass was reviewed and **four errors were found**. They are
recorded here, and in §VII-C of the proposal itself, because a corrections
record is worth more than a clean-looking table.

| | First pass | Corrected |
|---|--:|--:|
| B — efficiency only | 2,59,001 | **2,63,401** |
| C — + indigenisation trade | 2,07,295 | **2,37,081** |
| D — floor | 1,29,632 | **1,83,640** |

**1. Option C was labelled with the wrong penalty.** It was marked as losing
~125 geolocation points. It does not: C keeps RTK and only deletes the
*moving-baseline heading* receiver. Substituting the magnetometer-class attitude
allocation from `sizing-calculations.md` §11 into the case-C budget moves the
total from **1.304 m to 1.322 m** — an 18 mm degradation. The 125-point penalty
belongs to Option D, which deletes RTK itself.

**2. The motor saving was circular.** It booked ₹8,396 by pricing the motor at
₹7,000 — a figure the same study argues is *below the lowest listing found*
(₹9,099). Withdrawn; the motor is now 9,099 in every column.

**3. The ESC saving was a specification failure.** ₹1,600 was booked against a
part whose catalogue advertises 30–45 A for a 60 A requirement. Withdrawn.

**4. Compliance was treated as optional.** The sub-GHz radio was priced at
₹1,560 (a 433 MHz kit) in the lowest option while the same document argued that
figure does not buy a compliant 865–867 MHz link. The compliant ₹19,355 is now
carried in **every** column — a legal band is not an option-level choice.

Net effect: the floor moved **up** by ₹54,008. That strengthens the conclusion
rather than weakening it — an aircraft that flies this mission is further from
₹1,00,000 than the first estimate suggested.

**One finding survived and improved.** Option B raises indigenous content from
58 % to 61 %, because the line it shrinks is the imported accelerator. Cost
reduction and indigenisation are usually opposed; on this one step they are not.

## The abort path names its mechanism, and the mechanism has a trap

Deleting the sub-GHz safety radio rests entirely on the ExpressLRS link carrying
**both** safety-pilot control and the abort path. The proposal asserted that and
never said how, which left a load-bearing claim uncheckable.

It now names the mode, because **only one of the two available modes actually
works this way**:

| ELRS mode | RC control | MAVLink telemetry | Verdict |
|---|---|---|---|
| **Native MAVLink (3.5+)** | yes | yes | **required** — one link, one UART |
| AirPort (older) | **no** | yes | **breaks the deferral** |

AirPort is a transparent serial bridge that *consumes* the link. A build
configured that way has telemetry and no control, and needs a **second radio**
to fly. That is not theoretical: the widely-followed build video "Building a sub
250g Autonomous Drone with Ardupilot and ExpressLRS AirPort Telemetry" hits this
exact wall and solves it by buying a second ELRS pair **at 868 MHz** — which is
the sub-gigahertz set this budget deletes.

**So: configured wrongly, the deferral is not a saving, it is a defect** — and
it surfaces at integration, not at review. The requirement is recorded on the
receiver line in `competition_budget.py` so it travels with the BOM rather than
living only in prose.

Native MAVLink is independently tested to 126 km without failsafe, against our
600 m geofence.

**Consequence now stated in the proposal:** the abort path inherits the link's
availability. An outage removes the operator's fastest intervention until the
link returns or the 60 s link-loss timer fires the autonomous return. The
aircraft is never without *a* recovery path; it can be briefly without an
*operator-commanded* one. Measuring outage against range and attitude is a P6
objective.

## Flight-controller options, priced

There are no development mules in the funded build — the three aircraft *are*
the competition set — so "cheap board on the mules" does not map to a budget
line. What does map is the deferred spare.

| | Ask | vs. status quo | Spare-FC risk |
|---|--:|--:|---|
| **A** Pixhawk x3, spare deferred *(current)* | 8.24 L | — | accepted |
| **B** Matek x3, spare deferred | **7.81 L** | −0.43 L | accepted |
| **C** Pixhawk x3 + one Matek **as the spare** | 8.36 L | +0.12 L | **retired** |
| **D** Matek x3 + one Matek spare | 7.92 L | −0.32 L | **retired** |

Holybro Pixhawk 6C Mini **₹22,600** against Matek H743-WING/SLIM
**₹8,999–10,656** — same STM32H743 at 480 MHz, same ArduPilot feature set, 7
UARTs. The real trade is the Pixhawk connector standard and on-board IMU
vibration isolation, not capability. Radiolink CrossFlight was checked and is
**₹30,400** — more expensive than what we already have, so it is not a candidate.

**Option C is the interesting one**: it retires an accepted risk (`Spare flight
controller — 26,000 — DEFERRED`) for ₹10,000 rather than ₹26,000, and the spare
doubles as the bench board. It costs 0.12 L instead of saving 0.43 L.

## Battery failsafe is staged

Reserve threshold commands RTL; a second, lower threshold commands immediate
landing where the aircraft stands. A pack that cannot reach the pad should land
under control at the point it admits this, rather than descend uncommanded
partway home.

## Two text defects visible in the ground-station screenshot

The proposal now uses the restyled dashboard (`ground-station/gcs-dashboard.png`,
copied from `frontend/public/Drikr NIDAR Dashboard.png` under a filename LaTeX
can handle). It is a real capture of the running system — Leaflet attribution,
live tiles, three decoded feeds — not a render, which is why it is usable as
evidence at all.

**Two strings in the UI need fixing in NIDAR-GSC before this goes to a sponsor.
They are visible at full size in the figure.**

| Shown | Should read |
|---|---|
| `NSSSION WINDOW` | `MISSION WINDOW` |
| `MTI EMERGENCY: Bus safety route configured.` | something coherent — the previous build read `NOT IMPLEMENTED — no safety radio configured` |

The second matters more than a typo. The old wording stated a real limitation
clearly; the new one is garbled, and a reviewer reading "Bus safety route
configured" next to a disabled ABORT button will not know what is being claimed.
The rest of that panel is still correct and admirably blunt: *"These buttons
record intent to the mission log but transmit nothing. Recover the aircraft with
the safety pilot's RC."*

**The frontend source is not in this repository.** `ground-station/frontend/`
holds only `.gitkeep` and `public/`; the UI lives in NIDAR-GSC. These two fixes
have to be made there.

## The take-off delays do not appear in the telemetry as commanded

Re-rendering the launch figure from the raw recording surfaced this. The mission
file sets `NAV_DELAY` to **0 / 15 / 30 s** before each take-off, and the
autopilots log it — `Delaying 15 sec`, `Delaying 30 sec`. But the aircraft are
observed leaving the pad at:

| aircraft | commanded | logged take-off | first altitude > 2 m |
|---|--:|--:|--:|
| 1 | 0 s | 0.00 s | 0.00 s |
| 2 | 15 s | 2.80 s | 3.50 s |
| 3 | 30 s | 9.40 s | 10.01 s |

Aircraft 3 delayed 9.2 s against a commanded 30; aircraft 2 delayed 2.7 s
against a commanded 15. The ratios are not consistent with each other, so this
is not simply a `SIM_SPEEDUP` time-base conversion.

**The supporting argument here was wrong and has been replaced.** This
previously read "`done_at` of 626 s is consistent with `t` being simulated
seconds." That figure is an artifact. Building the dashboard replay surfaced
**exactly one interval in the 346-sample recording that exceeds 5 s: index 328
jumps 453.93 s**, against a median interval of 0.500 s. The aircraft state does
not jump with it — drone 3 descends 13.9 → 11.6 m across the boundary, the same
2.25 m per sample it was doing either side, while drones 1 and 2 sit frozen at
identical altitude and identical mAh. The recorder's clock moved; the vehicles
did not. **Physical duration is 172.4 s, not 626 s.**

The conclusion survives on better evidence. Drone 3 drew **2,082 mAh**. Over
172 s that is 43.5 A average, the right order for hovering a 6.36 kg aircraft;
over 626 s it would be 12 A, which that aircraft cannot hover on. So the mAh
counter — which integrates over *simulated* time — independently puts the flight
at about 172 s, and `t` does track simulated seconds after all.

**That makes the NAV_DELAY finding stronger, not weaker.** If `t` is simulated
seconds, commanded delays of 0/15/30 s should appear as take-offs at 0/15/30 s.
They appear at 0/2.8/9.4. There is no time-base conversion left to explain it
away: the delays are genuinely not being served.

**The deconfliction still works** — closest airborne pair goes 1.31 m → 64.80 m,
and that is measured, not assumed. What is unverified is the *mechanism*: the
document says the spacing comes from a 0/15/30 s stagger, and the recording does
not show those delays being served.

The figure therefore plots **observed** lift-off, not commanded. Two things are
worth doing before this is quoted as evidence of the mechanism:

1. Establish whether `t` in the recording is simulated or wall-clock time.
   `sim-flight.sh` and the recorder are the places to look.
2. Re-fly at `SIM_SPEEDUP 1`. If the delays are served correctly there, this is
   a simulation artefact; if they are not, `NAV_DELAY` is not doing what the
   mission file says — which would be the fifth instance of the defect class in
   `HANDOFF.md` §5.

## Separation numbers: HANDOFF.md is stale

Writing the figure captions meant recomputing the separation results from
[`mission-telemetry.json`](../../simulations/recordings/). **Three numbers in
`HANDOFF.md` §2 do not reproduce**, and one of them is definitively wrong:

| Claim | HANDOFF.md | Reproduced from telemetry | Also says |
|---|--:|--:|---|
| Separation at launch | 92.12 m | **64.80 m** | `README.md` and the figure itself both say 64.80 m |
| Separation en route | 34.00 m | 29.19 m | definition-sensitive |
| Stacked over the pad | 6.52 m | 5.51 m | hardcoded as a caption string in `proof_figures.py:350` |

The launch figure is not a definition question: `README.md`, `proof-1-launch.png`
and the raw telemetry all agree on **64.80 m**, and only `HANDOFF.md` says
92.12 m. That one has been corrected in place.

The other two depend on how the phase boundary is drawn — my "en route" excludes
a 60 m radius around the pad — so they are **left alone pending a decision on the
definition**, not silently overwritten. The recovery figure is worth attention
because `proof_figures.py` carries it as a hardcoded string in a caption rather
than computing it, which is the failure mode this repository is organised
against.

The proposal uses only the reproducible figures.

## The proposal flies at 60 m; the simulation flies at 40 m

Adding the processing-pipeline section surfaced this. The design point table
says **Survey altitude 60 m AGL**, the geolocation budget is computed at 60 m,
and Fig. 5 draws the sweep as "60 m AGL". But every committed recording was
flown at **40 m** — `fly_and_record.py` passes `altitude_m=40.0`, the telemetry
carries `search_alt: 40.0`, and the median cruise altitude is 40.6 m.

So the flight evidence in Section VI does not describe the aircraft in Table I.

**Neither number is obviously wrong, which is why this is recorded rather than
patched.** `docs/sizing/configuration-trade.md` §5.3 explicitly *proposes*
re-baselining to 40 m — it buys 50 % more pixels on target (140 px against
93 px) for 56 s of an 1800 s budget — but marks it **PROPOSED pending a P7
recall-vs-GSD measurement**, not adopted. The simulation harness appears to
have moved to the proposed value while the proposal stayed on the old one.

Changing it is not a one-line edit. Survey altitude sets swath, which sets line
spacing, transect count, sweep time and the whole geolocation error budget, and
the perception subsection's 2 cm/px → 85 px → 47 px chain is computed at 60 m.
**Whichever way this resolves, Table I, Section IV-C, Section IV-D and Fig. 5
have to move together.**

## Open issues a reader should know about

**The design point is contested.** This document uses the **18 in / 6.36 kg**
configuration from [`docs/sizing/`](../sizing/). The verified BOM
([`RescueSwarm_BOM_India_Verified.xlsx`](../../hardware/bom/)) describes a
**17 in / 5.78 kg** aircraft, and its README says the design point was "revised
to fit real Indian parts". A header comment in the `.tex` flags this. **If the
17 in configuration is adopted, Table I and Section VII must change together** —
and the sizing model needs re-running, not just the numbers editing.

**Two references need checking against what was actually read.**
`mathisen2020airdrop` cites the deep-stall landing paper; the release-velocity
sensitivity result attributed to it in Section III-D should be verified against
the specific source before submission. `zhu2021visdrone` should be checked for
the correct volume and page range.

## Where the numbers come from

| Section | Source |
|---|---|
| Design point (Table I) | [`docs/sizing/model-output.txt`](../sizing/model-output.txt) |
| Geolocation budget (Table II) | [`docs/sizing/geotag-accuracy-output.txt`](../sizing/geotag-accuracy-output.txt) |
| Phases (Table III) | [`docs/development-plan.md`](../development-plan.md) |
| Cost options (Table IV) | [`RescueSwarm_Cost_Study.xlsx`](../../hardware/bom/) |
| Programme cost (Table V) | [`docs/sizing/cost-model-output.txt`](../sizing/cost-model-output.txt) |
| Preliminary results | [`HANDOFF.md`](../../HANDOFF.md) §2 evidence table |

Every figure in the proposal traces to one of these. If one of them moves, the
proposal is stale — there is no CI gate on this document, unlike the model
outputs it draws from.

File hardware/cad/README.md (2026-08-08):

# hardware/cad

## The frame is driven by the model, not by transcription

[`rescueswarm-frame-equations.txt`](rescueswarm-frame-equations.txt) is
**generated** by [`tools/sizing-model/cad_equations.py`](../../tools/sizing-model/cad_equations.py).
Do not edit it by hand.

### Why it exists

The battery bay in [`frame-design-constraints.md`](../../docs/frame-design-constraints.md)
specified a **12-cell 6S2P pack when the design point is 18 cells and 6S3P**. It
got there by being transcribed from the model into a document, after which the
model moved and the document didn't. A markdown table is cheap to correct; a
frame is not, and CAD is the next place that error lands.

So the driving dimensions come from a file the model writes.

### Getting the variables into a part

**Use the script.** From the repo root, with SolidWorks installed:

```
python tools/cad/sw_build_skeleton.py
```

It launches SolidWorks, creates a part in MMGS, pushes all 25 variables in, and
draws the layout sketch. **Then immediately `Save As` under your own filename**
and model from there — the generated `rescueswarm-skeleton.SLDPRT` is
gitignored and will be overwritten the next time anyone runs the script.

> **The external-file link does not work through the API, and this was tested.**
> `IEquationMgr.FilePath` and `.LinkToFile` can both be set and SolidWorks reads
> them back correctly, but the equations are never imported: **count stays 0**
> across every ordering, every encoding (utf-8, utf-8-sig, utf-16, ansi) and a
> forced rebuild. `Add2` works and accepts exactly the syntax this file uses, so
> the script pushes the variables in directly.
>
> Linking the file **through the UI** (Tools → Equations → Link to external
> file) is the documented workflow and probably does work — but **I have not
> verified it**, so treat it as untested. If it does work for you it is the
> better option, because the variables then update on rebuild instead of
> needing the script re-run.

Once the variables exist, drive sketch dimensions by expression instead of
typing numbers:

   | dimension | expression |
   |:--|:--|
   | motor mount circle, from centre | `= "wheelbase_diag" / 2` |
   | battery pocket length | `= "bay_length"` |
   | magazine cut-out | `= "magazine_length"` |
   | camera mount hole spacing | `= "cam_fastener_spacing"` |

Change the pack → re-run `cad_equations.py` → re-run `sw_build_skeleton.py` (or
rebuild, if you got the UI link working). The frame follows. Nobody retypes 761.

### What the skeleton contains

Reference geometry only — no solids. It is the layout other parts mate to:

- four motor axes at `"wheelbase_diag"/2` on the diagonals
- prop-tip circles at `"prop_dia_max"/2`, so tip clearance is **visible** rather
  than trusted (30 mm at 20 in)
- battery bay footprint, 140 × 84 mm
- magazine footprint, 400 × 200 mm
- overall footprint, 1046 mm square

Verified by closing the part, reopening it from disk and reading it back:
**25 of 25 variables match the generated file exactly**, and `Sketch1` plus the
`Equations` folder are present.

### File format

Plain text, one variable per line, `'` for comments:

```
' PROPULSION GEOMETRY
"wheelbase_diag"= 760.847
"arm_length"= 380.423
```

Values are in **document units** — set the part to **MMGS** before linking, or
every dimension will be out by 25.4.

### What CI enforces

The reproduce job runs the generator and fails if either:

- the CAD parameters no longer agree with `docs/sizing/model-output.txt` — the
  generator parses the pack topology and cell count out of the committed model
  output and refuses to emit a file for the wrong aircraft; or
- the committed equations file differs from what the generator produces, i.e.
  someone edited it by hand or changed the model without regenerating.

Verified to fail: reverting the model output to 6S2P/12 cells produces

```
CAD EQUATIONS DO NOT MATCH THE MODEL:
   pack topology: model 6S2P, this script 6S3P
   cell count: model 12, this script 18
```

### Two numbers worth reading before you start modelling

- **`cam_max_differential` = 0.214 mm.** That is the *total* differential
  movement allowed across the camera mount's 80 mm fastener spacing, for the
  life of the airframe. An M3 clearance hole carries 0.2–0.4 mm of slop on its
  own — which is why constraint #6 is dowels or a bond, not bolt friction.
- **`bay_depth` = 72 mm** against 48 mm for the superseded 6S2P. Take those
  24 mm by making the tray **wider or longer, not deeper** — the pack CG belongs
  in the rotor plane ([`cg_budget.py`](../../tools/sizing-model/cg_budget.py)).

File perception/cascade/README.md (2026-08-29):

# Cascade experiment — can a cheap gate buy us native-resolution tiling?

## The question

Our pipeline downsamples 2× before tiling, which cuts 48 crops to 12 but puts a
survivor at **~19 px** — TinyPerson's `tiny3` band, the hardest scale the
literature reports. Tiling at native resolution puts them at **~39 px**, outside
that band entirely, but costs 4× the compute.

**The proposal:** pay for native resolution by not running the detector on empty
water. A cheap binary gate looks at every tile and decides which are worth the
expensive pass.

**The question this experiment answers:** can a gate reject enough tiles to make
native tiling cost what downsampled tiling costs today, without dropping
survivors?

## Run it

```bash
python perception/cascade/run_experiment.py            # Stage 0, needs nothing
python perception/cascade/economics.py                 # the decision rule
python -m pytest perception/tests/test_cascade.py -q   # 27 tests, no GPU

# when you are ready to spend the fortnight
python -m perception.cascade.fetch_data --dest data/seadronessee
python perception/cascade/run_experiment.py --ann data/seadronessee/annotations/instances_train.json
```

`fetch_data.py` refuses to declare the data usable unless **gimbal pitch is
present on at least half the images**. That is not fussiness: a re-hosted copy
converted to YOLO format keeps the boxes and drops the metadata, and without
gimbal pitch we cannot exclude oblique frames. Every oblique frame that leaks
into the set makes the measured recall belong to an easier problem than the one
we fly — and the result would look good and mean nothing.

**Running Stage 1 on a university GPU: see [RUNBOOK.md](RUNBOOK.md)** for the
download link, the cluster session, and the order to do things in.

## The decision rule, fixed before any result

Adopt **only if both hold** on held-out data:

1. **Tile rejection ≥ 80.5%** — below that the cascade costs more than the
   downsampled pipeline it replaces.
2. **Per-target recall ≥ 90%** (SYS-07) with gate failures assumed **fully
   correlated** across the pass.

The second condition is the one that matters. Twelve *independent* looks at 50%
recall find 99.98% of targets; twelve *correlated* looks at 50% find 50%. A
survivor whose appearance the gate reads as water reads as water in every frame
— so fusion rescues nothing, and the failure is invisible from the air and
unrecoverable afterwards. **Report per-target recall, never per-tile.**

## What Stage 0 already told us

The rejection *ceiling* is not the constraint. With 48 tiles per frame and a
target spanning at most two, even three survivors in one frame leaves **87.5%**
of tiles empty, against an 80.5% break-even. There are plenty of empty tiles.

**The open question is whether a gate can find them at recall ≈ 1.0.** That
needs data.

## Two results worth knowing before designing the gate

**Gate cost barely matters.** Break-even moves 75.3% → 80.5% across a 16×
range of gate cost, because the detector dominates so completely. There is
therefore **no reason to cripple the gate's input resolution** to save compute.

That matters because a 128×160 MCU-class gate turns our 39 px target into
**9.7 px** — it would make an unrecoverable decision at the resolution where
published AP is worst. Use a 640-input gate; it costs 5 points of rejection and
sees the target at full size. This is why the cascade runs on the Hailo and
**not** on a microcontroller.

**25% overlap costs +12.5%, not +31%.** The naive `ceil(H/stride)` overcounts,
because the last tile covers a full tile rather than a stride. Correct count is
`ceil((H−tile)/stride)+1`: 48 → 54 tiles. SAHI's 25% recommendation is much
cheaper than it first appears. A test asserts this.

## Data

[SeaDronesSee ODv2](https://github.com/Ben93kie/SeaDronesSee) — 12.7 GB, 14,227
images, COCO JSON, humans in open water with per-frame altitude and gimbal
pitch. Test-set ground truth is withheld, so held-out evaluation must come from
the val split or a re-split of train.

`dataset.py` does two things that make borrowed data mean something:

- **Excludes oblique frames** (>20° off nadir). Our geolocation is near-nadir
  only; a swimmer at 45° shows a body outline, ours shows head and shoulders.
  Keeping them would measure a problem we do not have.
- **Rescales every frame** so its targets are *our* pixel size. Upscaling adds
  no detail, so a gate measured this way can only look worse than it will on our
  optics — the right direction for an error to point.

## Status

| Part | State |
|---|---|
| `geometry.py` — tiling, scale matching, tile labelling | done, tested |
| `economics.py` — break-even, correlated-recall model, decision rule | done, tested |
| `dataset.py` — SeaDronesSee loader and frame selection | done, tested on synthetic COCO |
| `run_experiment.py` Stage 0 — rejection ceiling | done, runs |
| `fetch_data.py` — download and verification | verify tested on synthetic COCO; **download path unrun** |
| `gate.py` — training, threshold, scoring | metric logic tested; **training loop unrun** |
| Stage 1 — actually run it | **needs Kaggle credentials, ~25 GB free, and a GPU** |

### What Stage 1 still needs from you

- **Kaggle credentials** (`~/.kaggle/kaggle.json`) or a manual download from
  the official source.
- **~25 GB free disk.** A 12.7 GB archive plus its unpacked copy.
- **A GPU.** ~14k frames × 48 tiles on CPU is days, not hours. `gate.py` warns
  and continues rather than refusing.

### What `gate.py` cannot measure, and why it matters

The decision rule assumes gate failures may be **fully correlated** across a
pass. Object Detection v2 is independent images with no track IDs, so
correlation is not observable in it. The real measurement needs the
**SeaDronesSee MOT split**, where the same identity can be followed across
consecutive frames.

Until that is done, a passing per-target recall on ODv2 is necessary but not
sufficient — and `report()` prints that caveat with every result so it cannot
quietly become a claim.

Stage 1 is the part that costs a fortnight. Stage 0 costs half an hour and is
what decides whether the fortnight is worth spending — which is why it runs
first and why the decision rule was written before any result existed.

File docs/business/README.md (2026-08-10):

# RescueSwarm — Business Strategy (Phase 4B)

**200 points — exactly as many as the entire Design Review, and 20 % of the
1000-point total.** Nothing in this repository addressed it before this file
existed. It is scored as a startup pitch (4.22): the team presents its drone
system as a viable business proposition, 15 minutes plus 10 for questions.

**This is a skeleton, not an answer.** Each section states what is scored, what
we can already support from work in this repo, and what has to be gathered.
Items marked ⏳ have **lead time** and cannot be produced in the final week.

---

## Scored parameters (rulebook §9, M1 Phase 4B)

| # | Parameter | Max | Status |
|---|---|---|---|
| 1 | Problem Understanding & Real-World Relevance | 30 | Strong — see §1 |
| 2 | Target Users, Customers & Beneficiaries | 20 | To draft |
| 3 | Market Sizing & Deployment Potential | 30 | To research — sources named in [cost-and-economics.md](cost-and-economics.md) §5 |
| 4 | Business Model & Revenue Approach | 30 | Cost basis ready (14.60 L/system); pricing needs §5 inputs |
| 5 | Expenditure Breakdown & Resource Planning | 20 | ✅ **Done** — [cost-and-economics.md](cost-and-economics.md), generated from the BOM |
| 6 | Funds Raised, Sponsorships & Resource Mobilisation | 20 | ⏳ **Lead time** |
| 7 | Competitive Advantage & Differentiation | 20 | Strong — see §7 |
| 8 | Go-to-Market Strategy & Partnership | 20 | ⏳ Partner conversations have lead time |
| 9 | Regulatory, Safety & Adoption Readiness | 10 | To draft — DGCA framework |

---

## 1. Problem understanding (30)

The strongest section, because it is already evidenced. Flood response in India
is a recurring, quantifiable problem, and the engineering work in
[`../sizing/`](../sizing/) demonstrates understanding well beyond the pitch level.

**Use the engineering as proof of understanding.** The five findings in the
README — that the mission is not coverage-limited, that setup is the only tight
constraint, that release velocity dominates drop accuracy — are exactly the kind
of non-obvious insight that distinguishes a team that has actually modelled the
problem from one that has described it.

**To gather:** NDRF/SDRF deployment statistics, flood-affected area and
displacement figures for recent Indian flood events, current search-and-rescue
response times.

## 2. Target users (20)

Candidate segments, to be narrowed to a primary:
- **NDRF / SDRF** — national and state disaster response forces
- **District disaster management authorities** — first responders on scene
- **Coast Guard and inland waterway authorities**
- **Large industrial sites** with on-site emergency response obligations

Distinguish **buyer** (procurement authority), **user** (the two-person crew),
and **beneficiary** (survivors). The scoring lists all three.

## 3. Market sizing (30)

Build **bottom-up**, not top-down — bottom-up sizing is far more defensible under
questioning. Structure: number of districts with flood exposure × systems per
district × replacement cycle, plus a services/training component. State the
assumptions explicitly and show the sensitivity.

**To research:** Indian drone market size and growth, government disaster
management budget allocations, existing procurement precedents.

## 4. Business model (30)

Options to evaluate — pick one and defend it:
- **Hardware sale** with annual maintenance
- **Lease / drone-as-a-service** to district authorities
- **Capability contract** — guaranteed response readiness

The indigenisation position matters commercially, not only for scoring: public
procurement in India increasingly favours domestic content, so the 95.5 % Indian
supplier figure is a **sales argument**, not just a compliance one.

## 5. Expenditure breakdown (20) — ⚠ required deliverable

Rule 7.5 requires **a detailed cost sheet in addition to the BOM**. The BOM
exists in [`../../hardware/bom/`](../../hardware/bom/); the cost sheet does not.

See [`cost-sheet.md`](cost-sheet.md) for the required structure. It must cover
all costs incurred in designing, developing, integrating and testing — not just
flight hardware. Development tooling, test consumables, travel to the finals and
crashed-airframe replacements all count and are commonly forgotten.

## 6. Funds raised and sponsorship (20) — ⏳ lead time

**Start now.** This is the section most likely to score zero by default, and the
only one that cannot be written up at the last minute. Institutional grants,
departmental support, component sponsorship from Indian suppliers already on the
BOM, and incubator support all count. Suppliers listed in the README
(Bharath Components, Mechtex, Flameback Tech, Zuppa, e-con Systems, and others)
have a direct interest in an indigenous system that showcases their parts.

**Keep evidence** — emails, letters of support, invoices. Claims without
evidence do not score.

## 7. Competitive advantage (20)

The genuine differentiators, all evidenced in this repo:
- **A closed engineering model** where every published number is reproducible
  from committed code. Very few student teams can say this.
- **Read-only GCS by construction** — the rule violation is structurally
  impossible rather than avoided by discipline.
- **Indigenous supply chain** with an honest dual-basis score (95.5 % of line
  items, 60.2 % of value) rather than a single flattering number.
- **Decisions traceable to analysis**, including documented reversals — see
  [`../sizing/configuration-trade.md`](../sizing/configuration-trade.md).

Honesty about what is *not* Indian (AI inference silicon, high-drain cells, RF
chipsets, high-current connectors) is a credibility asset under jury
questioning, not a weakness.

**Name the two deliberate scope limits before a juror finds them**, so they read
as engineering judgement rather than oversight:

- **RGB-only sensing.** Correct for this competition — the targets are
  human-looking dummies scored in daylight, and thermal detects body heat a
  mannequin does not have. For real flood response, thermal is a genuine
  roadmap item: live humans emit heat and it works at night.
- **GNSS-dependent navigation.** The 450-point accuracy case rests on RTK. Real
  deployments face jamming, urban canyon and indoor voids — and NIDAR's own
  Mission 2 is explicitly GPS-denied. Visual-inertial odometry as a GNSS
  fallback is the natural next capability, and saying so costs nothing now.

## 8. Go-to-market (20) — ⏳ partner lead time

Pilot-first: one district authority, one monsoon season, measured outcomes.
Identify a named partner if at all possible — a real letter of intent scores
very differently from a hypothetical.

## 9. Regulatory and adoption readiness (10)

Cover the **DGCA Drone Rules 2021** framework: UIN registration, remote pilot
certification, airspace zones (green/yellow/red), and BVLOS status. Note honestly
where autonomous swarm operation sits relative to current regulation and what
would be required for operational deployment.

---

## Preparation sequence

| When | Action |
|---|---|
| **Now (P0–P1)** | Begin sponsorship and institutional-funding conversations (§6). Longest lead. |
| P1–P2 | Start the cost sheet and keep it current as procurement happens — reconstructing it later is far harder |
| P3 (Oct review) | Draft market sizing and business model |
| P4–P6 | Partner and pilot conversations (§8) |
| P8 (Dec review) | Full draft, rehearsed |
| P10 | Final rehearsal with Q&A practice — 10 of the 25 minutes are questions |

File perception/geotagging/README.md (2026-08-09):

# geotagging

**Pixel to lat/lon. This gates 450 of the 600 flight points.**

Detection and geotagging are one scored item worth 250 (SYS-07, SYS-12), and
delivery accuracy is a further 200 aimed *using* the geotag. The difference
between doing this naively and doing it properly is about **102 points**:

| case | geotag | pts/drop | 10 drops |
|:--|--:|--:|--:|
| A — no RTK, single frame | 3.09 m | 7.5 | 75 |
| B — RTK, single frame | 1.36 m | 15.7 | 157 |
| C — RTK + fusion + calibrated | 1.00 m | 17.7 | **177** |

**None of that gap is recoverable by a better detector.**

## What is here

`geotag.py` — pure geometry. No I/O, no camera, no autopilot.

```python
tag = project(detection, pose, camera)       # -> lat, lon, fix, sigma
tracker.add(tag)                             # cluster + inverse-variance fuse
tracker.confirmed()                          # survivors seen >= 3 times
```

- **`project()`** — pixel → camera ray → body → NED → intersect the ground
  plane → lat/lon. Enforces the **SYS-33 20° off-nadir gate** by refusing the
  detection rather than tagging it badly: a bad tag still consumes a delivery,
  so it is worth less than no tag.
- **`sigma_for()`** — 1σ horizontal for fusion weighting and the operator's
  display. Floored by the systematic terms (0.70 unmodelled, 0.50 target
  extent, 0.16 boresight, 0.10 lever arm) because **multi-frame fusion cannot
  average those away**.
- **`SurvivorTracker`** — the B → C step, worth ~20 points per drop.
  Inverse-variance weighted, and the reported fix is the **best ever seen**,
  not the latest — a later `RTK_FLOAT` tag is metres worse than an earlier
  `RTK_FIXED` one, and the ground station ranks on fix quality for the same
  reason.

## What is NOT here

- **Calibration (SYS-48).** Boresight and lever arm must be measured before any
  accuracy claim is valid. The mount tolerance that makes it hold is
  [`boresight_budget.py`](../../tools/sizing-model/boresight_budget.py):
  **0.21 mm over an 80 mm fastener spacing, for life.**
- **The detector.** Owned separately — see
  [`perception-integration-plan.md`](../../docs/perception-integration-plan.md)
  for the `Detection` contract this consumes.
- **Terrain.** The ground is a plane at `pose.agl_m`. On a flood plain that is
  reasonable; it is an assumption, not a fact.

## The thing most likely to be got wrong

**`t_capture` must be the camera exposure time, not when the frame arrived.**
At 8 m/s a 100 ms timestamp error is **0.8 m** on the ground — comparable to the
entire 0.91 m budget. Pose is interpolated to that instant, and nothing
downstream can recover a wrong one.

## Tests

```
cd perception && python -m pytest tests -q      # 17 tests
```

A projection bug does not crash — it puts the survivor somewhere plausible and
wrong. So every test has a hand-computable answer, and the suite was
**falsified against three injected bugs**: swapped camera axes, flipped east
sign, and yaw ignored. It caught all three (5, 3 and 1 failures respectively).

Next step for verification: score `project()` against **Gazebo ground truth**.
The simulator knows the true position of every object, so the geotag can be
checked to centimetres automatically — see
[`gz-flight.sh`](https://github.com/tetraethylmethane/NIDAR-GSC/blob/main/scripts/gz-flight.sh).

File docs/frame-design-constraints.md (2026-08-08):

# Frame Design Constraints
### What CAD needs before the first part is cut

> **Drawing the frame?** Start with the
> [**CAD brief**](../hardware/cad/CAD-BRIEF.md) — same content, ordered for
> someone about to open SolidWorks, with the workflow and the order of work.
> This document remains the binding list.

Everything here is expensive or impossible to retrofit. Decide these before the
frame is designed, not after.

---

## 1. Decided

| # | Constraint | Value | Why |
|---|---|---|---|
| 1 | **Configuration** | **Quadrotor, 4 arms** | Physics marginally favours hex/octo, but a hex is 50 % more propulsion integration across three aircraft and an octo is double, on a 21-week calendar with no flight code written. See [configuration-trade](sizing/configuration-trade.md) §2.4. **Revisit only if organiser Q3 says motor-out tolerance is required.** |
| 2 | **Arms accept 16–20 in props** | Wheelbase sized for 20 in with 30 mm tip clearance → **761 mm diagonal** | Prop diameter is provisionally 18 in but settles on a bench in P5. Late-binding costs nothing now and everything later. |
| 2a | **Folding arms are ALLOWED, with a hard budget** | Deploy + lock + **verify** in **≤ 22 s per aircraft**. Folds strictly **outboard** of the camera/IMU/GNSS core | Measured, not assumed — [`setup_budget.py`](../tools/sizing-model/setup_budget.py). Deployment is *free* up to 22 s because it hides in the 75 s companion-boot shadow; the crew are not the critical path. It goes over the window at 30 s, and 28 s only "passes" by 1 s, which is a coin toss rather than margin. **22 s needs quick-release clamps and a lock indicator visible from a metre away — it is not achievable with bolts.** The launch box does not force this either way: three aircraft unfolded at 1046 mm sit in 3138 mm, inside the 3.66 m box. Folding buys transport volume only, ~944 mm → ~450 mm. |
| 3 | **Battery bay** | **6S3P, 18 × 21700, 1449 g.** Bare cell block ≈ **126 × 70 × 63 mm** (6 across × 3 deep, cells lying down); allow **140 × 84 × 72 mm** with holders, wrap, BMS and leads, including ~15 % growth on the depth axis — take these from [`rescueswarm-frame-equations.txt`](../hardware/cad/rescueswarm-frame-equations.txt) (`bay_length`, `bay_width`, `bay_depth`), not from this table | ⚠ **This entry previously said 6S2P, 12 cells, 966 g.** That was the pre-BOM design point. With real Indian component masses (+471 g/aircraft) the 6S2P pack **fails the ≥2.0× endurance reserve at 1.78×**; 6S3P makes it at 2.05×. The change is **+6 cells and +483 g** — a whole extra row. The old "~20 % volume growth" allowance covered 14.4 cells, so a bay built to the old entry **could not take the real pack even with its stated margin**. Authoritative source: [`sizing/model-output.txt`](sizing/model-output.txt). |
| 4 | **Payload magazine** | 4 kits, each 200 × 100 × 50 mm, 200 g. **Lay it out for packaging and drop-path clearance, not for CG** — centre the group on the CG and stop there | Fixed by rule — MB §2. Can be designed and built today, independent of everything else. CG was checked rather than assumed ([`cg_budget.py`](../tools/sizing-model/cg_budget.py)): across a 2×2 and two row layouts, peak CG excursion during release is **3.7–4.0 mm at best order and 7.4 mm at worst — under 4 % of hover thrust either way.** Layout is worth 0.3 mm; *release order* is worth twice as much, and that is autonomy's decision, not CAD's. |
| 4a | **Battery tray** | **Side-loading, captive latch, hard stop.** Repeatable position, not adjustable | The pack is the heaviest item at 22.8 % of MTOW, so its seating repeatability *is* the trim repeatability — a 10 mm placement error is 2.3 mm of CG and ~1.2 % permanent trim. Side loading also keeps a pack swap clear of the parachute mount above and the magazine below, and off the setup critical path. |
| 4b | **Vertical CG** | Pack CG **in the rotor plane**, not slung beneath it | Hanging the heaviest item low for "stability" is a fixed-wing instinct that misfires on a multirotor: the rotors are the control effectors, and a CG well below them makes a pendulum the controller fights, coupling attitude into translation during exactly the slow precise hover a delivery needs. The extra 21 mm the 6S3P block needs over 6S2P should be taken by making the tray **wider or longer, not deeper**. |
| 5 | **Parachute mount** | Top-centre, clear deployment cone, no prop or antenna in the path | Permitted and worth fitting (SYS-41). **Must be designed in** — a retrofitted mount fouls props or deploys into an arm. |

## 2. Constraints that come from the accuracy budget

Geotagging is 75–83 % of the delivery error budget and gates 450 of the 600 flight
points. Three of its terms are decided by *mechanical design*, not software:

| # | Constraint | Requirement |
|---|---|---|
| 6 | **Camera mount rigidity** | **0.21 mm of differential movement over an 80 mm fastener spacing — total, for the life of the airframe.** Dowelled or bonded; **not** bolt friction. Kinematic or CF bracket so thermal growth translates rather than rotates. |
| 7 | **GNSS–camera lever arm** | A **measurable datum** — a defined feature callipers can reach, between antenna phase centre and camera mounting face. One dimension on a drawing. |
| 8 | **Dual GNSS antenna baseline** | As long as the frame allows, symmetric about the CG, clear of carbon and power wiring. Heading accuracy scales with baseline length. |

**Where #6 comes from, and what it is *not* for** ([`boresight_budget.py`](../tools/sizing-model/boresight_budget.py)):

The 0.16 m case-C boresight allocation is **0.153° at 60 m AGL**. Over an 80 mm
fastener spacing that is 0.21 mm of differential movement. An M3 clearance hole
has 0.2–0.4 mm of radial slop on its own, and one hard landing takes it up —
which is why this is a dowel-or-bond requirement rather than a preference.

But check the leverage before over-engineering it. At budget, boresight is
**3.3 % of geotag variance**; the 0.70 m unmodelled allowance (62.7 %) and the
0.50 m target-extent term (32.0 %) dominate. Tightening boresight *below* 0.16 m
buys essentially nothing:

| boresight | geotag RSS | delta |
|:--|--:|--:|
| 0.16 m (budget) | 0.884 m | — |
| 0.32 m | 0.93 m | +0.04 m |
| 0.64 m | 1.08 m | +0.20 m |
| 1.05 m (= 1° at 60 m) | 1.37 m | **+0.48 m** |

**So this is a failure-mode requirement, not an optimisation.** Design the mount
to *hold* whatever calibration you achieve. A shifted mount or a skipped
calibration costs ~0.5 m of geotag **silently** — nothing on the operator's
screen says the camera moved.

The lever arm is the same story inverted: measuring it to 1 cm instead of 10 cm
is worth **0.005 m**. It does not justify any design compromise — it justifies a
datum, so the 0.10 m is a budget line rather than a guess.

> **Thermal.** A 100 mm aluminium bracket on a CF plate moves 0.066 mm over a
> 30 K day–night swing — a third of the whole allowance if it becomes rotation.
> Calibrate at flight temperature, use CF, or constrain it kinematically.

## 3. Constraints from the mission

| # | Constraint | Requirement |
|---|---|---|
| 9 | **Footprint** | ≤ 1046 mm square at 20 in props. Three aircraft must sit inside a 3.66 m box with **no part outside during launch or landing** (rule 8.10, MB §7) |
| 10 | **Payload release** | Positive mechanical lock independent of servo power. A brownout must not drop a kit |
| 11 | **Compute bay airflow** | Fan on the **main bus, running at power-on** (SYS-53) — not gated on arming or flight mode. Inlet and outlet clear on the ground **and folded**. **Do not bolt the camera bracket to the compute bay.** Battery airflow separate |
| 12 | **Setup handling** | Unpack-to-armed is the binding constraint. Every fastener, connector and folding joint on the outside of this airframe is spending the 15 s of margin. Prefer captive fasteners, keyed connectors and folds that cannot be assembled wrongly |

**Why #11 says "at power-on"** ([`thermal_budget.py`](../tools/sizing-model/thermal_budget.py)):

The instinct is to let propwash cool everything and save the fan. It fails in
the one window that matters. During the 5-minute setup the avionics are powered,
the companion is booting and working, and **the props are stopped**.

A sealed 150 × 100 × 60 mm bay carrying 18 W reaches a **42.9 K** steady rise in
still air. Its time constant is 429 s, so across a 285 s setup it gets ~49 % of
the way there — about **56 °C of bay air on a 35 °C day, before the mission
starts**. That is air; silicon sits above it. A companion that throttles during
the search is a detection-rate problem that arrives late, under load, with
nothing on the operator's screen to explain it.

With a modest fan the rise is **10 K**. The flow needed is **3.3 CFM** — a 40 mm
fan on a fraction of a watt. **The cooling is not hard; remembering to power it
from the main bus at power-on is the whole requirement.**

Two couplings worth knowing:

- **Compute heat reaches the camera.** A sealed bay adds 0.068° of bracket
  rotation — 0.07 m at 60 m. Honestly, that is *nearly nothing* against the
  0.884 m geotag (it makes 0.887 m) and does not justify contorting the layout.
  It earns its line because it is **systematic** and tracks **compute load**, so
  it moves once the detector starts working. Calibrate cold, fly hot, and you
  get an unexplained bias in P7. The ask is free: don't share structure.
- **The battery is the opposite problem.** Pack I²R is **54 W in hover** — three
  times the companion — and ~0 W on the ground. So compute is hot when
  stationary, the battery when flying. A single "propwash cools everything"
  layout satisfies the pack and fails the bay.

---

## 3a. Two constraints that fight each other

These are not independent, and CAD has to resolve them together rather than
satisfying each in turn.

**Parachute cone vs GNSS antennas — both want the top centre.** #5 needs a clear
deployment cone straight up from top-centre with nothing in the path. #8 wants
two GNSS antennas symmetric about the CG, raised, clear of carbon. Antennas on
masts either side of centre are directly in the canopy's way, and a chute that
snags on an antenna mast is worse than no chute — it deploys asymmetrically and
takes the aircraft down inverted. **Resolve by putting the antennas on the arms
or on booms outboard of the cone**, keeping them symmetric about the CG, and
proving the cone clear with a swept-volume check in CAD rather than by eye.

**Folding joints vs boresight vs setup time.** Folds help transport and cost
setup seconds (#12). More importantly they must not sit between the camera and
the GNSS antennas: every folding joint in that load path is a lever-arm term
that changes each time the aircraft is unpacked, which breaks #6 and #7 and
invalidates SYS-48. **The camera, the IMU and the GNSS antenna mounts must all
be on one rigid core structure**, with folds only outboard of them.

## 4. Still open — do not let these block the build

| Question | Blocks | Workaround while waiting |
|---|---|---|
| Q3 — is motor-out tolerance required? | Configuration (#1) | Build the quad. If the answer forces hex, the payload, avionics and ground segment all carry over; only the frame and propulsion are lost. |
| Q1 — how is "correctly geotagged" verified? | How much to spend on absolute RTK accuracy | Nothing mechanical. Affects procedure, not structure. |

**Nothing else in this document is waiting on an answer.**

---

## 5. Build now, in parallel with the frame

None of this depends on the airframe existing:

- Payload magazine and release mechanism (#4, #10) — dimensions are fixed by rule
- Ground station, including the read-only architecture
- Autonomy stack and multi-instance SITL
- Perception pipeline and the KML parser
- The full avionics stack on a bench, which is also the setup-timing test rig

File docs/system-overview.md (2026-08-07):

# RescueSwarm — System Overview

The long-form description of how the system works. The README is the summary;
this is the detail behind it.

---

## Mission flow

```text
Launch (sequenced, one aircraft at a time)
   │
   ▼
Load Mission Boundary ──► DARP equal-area partition
   │
   ▼
Climb to search altitude · altitude-stratified per aircraft
   │
   ▼
Parallel Boustrophedon Sweep  ◄── constant groundspeed, wind-compensated
   │
   ▼
Detect Survivor ──► candidate
   │
   ▼
Confirm (≥3 frames or 2 agents) ──► confirmed survivor
   │
   ▼
Geotag ──► ray–ground intersection + multi-frame fusion
   │
   ▼
CBBA Auction ──► delivery task assigned to one drone
   │
   ▼
Transit · Descend to 6 m · Null groundspeed · Release
   │
   ▼
Next task, or Return to Home
   │
   ▼
Sequenced Recovery into the 3.66 m box
```

Search and delivery overlap. Drones don't wait for the sweep to finish before
starting deliveries.

---

## Architecture

```text
                    Ground Control Station
                    (read-only + abort/recall)
                              │
                    5.8 GHz mesh  ·  868 MHz safety link
                              │
        ┌─────────────────────┼─────────────────────┐
        │                     │                     │
     Drone A               Drone B               Drone C
        │                     │                     │
        └───── batman-adv mesh · replicated state ──┘
                  Search • Detect • Deliver
```

**The GCS is a view, not a controller.** Rule 8.16 makes any GCS-originated
retask a manual intervention worth −50 points, so the ground station is built
read-only by construction. The violation is structurally impossible rather than
avoided by discipline.

**Autonomy is hybrid:** centrally partitioned on the ground (deterministic,
inspectable, fast), decentrally executed in the air (survives link loss). A drone
that loses the mesh for 10 s continues its assigned bundle; at 60 s it returns
home. No behaviour requires the link to make progress.

---

## Methods and sources

Every algorithmic choice traces to published work rather than intuition.

| Layer | Method | Source |
|---|---|---|
| Area partitioning | DARP — equal-area, connected sub-regions anchored to a common launch point | Kapoutsis, Chatzichristofis & Kosmatopoulos, *JINT* 86 (2017) |
| Coverage within a region | Boustrophedon cellular decomposition, sweep along the longest axis | Choset, *Autonomous Robots* (2000) |
| Delivery task allocation | CBBA — consensus-based bundle auction, conflict-free over local comms | Choi, Brunet & How, *IEEE T-RO* 25(4) (2009) |
| Dynamic reallocation | Partial replanning variant, bounded reassignment on new detections | Buckman, Choi & How, *AIAA SciTech* (2019) |
| Small-object detection | SAHI tiled inference — recovers recall that whole-frame resizing destroys | Akyon, Altinuc & Temizel, *ICIP* (2022) |
| Detector training data | HERIDAL + SARD for pre-training, Indian field data for fine-tuning | Božić-Štulić et al.; Sambolek & Ivašić-Kos, *IEEE Access* (2021) |
| Airdrop error model | Release-velocity dominance in ballistic dispersion | Mathisen et al., *Autonomous Robots* (2020) |
| Mesh comms | batman-adv L2 mesh + sub-GHz safety channel | Marchese et al., *Drones* 5(2) (2021) |
| Propulsion sizing | Momentum theory with figure of merit (FM = 0.60) | Standard rotorcraft practice |
| Systems process | V-model with TRL gates, spiral overlay on high-uncertainty subsystems | NASA SE Handbook SP-2016-6105 |

---

## Perception

> **Terminology.** "SAR" in the dataset names below means **Search And Rescue**,
> not Synthetic Aperture Radar. HERIDAL and SARD are public aerial *photographic*
> datasets of people in search-and-rescue scenarios. **There is no radar on this
> aircraft.**

### Why a plain RGB camera

The only sensor is a **12 MP RGB camera with a 6 mm lens** (BOM tab 01, rows
35–36). That is a deliberate choice, not a default:

| Alternative | Why not |
|---|---|
| **Synthetic aperture radar** | Tens of kg and hundreds of watts. The whole aircraft is 5.88 kg with a 200 g payload allowance. Not physically possible in this class. |
| **Thermal / LWIR** | **It would fail on the actual targets.** The organisers confirmed survivors are *human-looking dummies*. A mannequin sits at ambient temperature, so a thermal camera sees no body-heat signature to separate it from the ground. Thermal detects the one thing these targets do not have. |
| **Lidar** | Gives structure, not identity. A prone human and a log are similar point clouds; and it adds mass and power for a problem RGB already solves. |

RGB also happens to be **required anyway**: rule 8.14 obliges the GCS to display a
live camera feed from every drone, so a camera is on the aircraft regardless of
what detects the survivors. And the mission is flown "under standard daylight
conditions" (MB §7), which removes the usual reason to reach for thermal or radar
— night capability.

Resolution is not the constraint either. CNN detectors need 20–30 px on target;
at 40 m this camera gives **140 px on a prone adult**, clearing that by 5×.

> **Product-roadmap note, not a competition change.** For *real* flood response,
> thermal is genuinely valuable — live humans emit heat and it works at night. The
> reason it is wrong here is specific to dummies being scored in daylight. Worth
> saying explicitly in the business pitch (§7 competitive advantage, §9 adoption
> readiness) rather than letting a jury assume RGB-only was an oversight.

### The detection problem

A COCO-pretrained person detector will fail here. Aerial search-and-rescue targets occupy
~0.1 % of frame area, lying prone or partially covered — a distribution general
detectors have never seen.

- **Pre-train** on HERIDAL and SARD, and reproduce the published baselines
  (YOLOv5L reaches ~0.90 P / ~0.89 R on HERIDAL) to prove the pipeline before
  trusting our own data.
- **Fine-tune on Indian field data.** HERIDAL and SARD are European — wrong
  terrain, vegetation, clothing and sun angle. Target ≥2,000 annotated frames
  from our own camera at our own altitude, with mannequins supine, prone, seated
  and partially occluded.
- **Tiled inference** at 2× downsample, 640 px tiles, 20 % overlap, 2 Hz.
- **Exploit the frame surplus.** At 8 m/s and 40 m the along-track footprint
  gives roughly a dozen looks per target per pass, so multi-frame fusion is
  effectively free — use it for temporal confirmation and for geolocation
  averaging.
- **Gate on body rate.** Suppress inference above 15 °/s: the imagery is smeared
  and the ground-plane assumption is worst in a bank. The turns fall outside the
  search region anyway.
- **Prefer near-nadir detections for geotagging.** The ground-height error term
  is `Δh·tan θ`, so a detection at the frame edge carries 0.62× the height error
  while one within 20° carries 0.36×. With a dozen looks available, edge
  detections can be discarded and re-acquired near nadir for free.

Detection recall is the long pole of the programme and is worth 250 of the 600
flight points. Field data collection starts in P1, not P5.

---

## Indigenisation

NIDAR exists to move India "from drone assembly to manufacturing the drone's
brain in India". This build takes that seriously and reports it honestly.

| Basis | Score |
|---|---|
| Line items with an Indian supplier | 95.5 % |
| Programme value that is Indian | 60.2 % |
| Flight-hardware value that is Indian | 56.8 % |
| Payload, kits and ground-truth targets | 100 % |

The gap between 95 % and 60 % isn't evasion. An Indian flight controller or
camera module is Indian design, firmware and manufacture on imported silicon, and
the BOM scores that at 60 % rather than 100 %. Always state which basis you're
quoting.

Two indigenisation choices that improve the system rather than compromise it:

- **NavIC.** ISRO's constellation sits directly overhead India — more satellites,
  faster time-to-first-fix (which buys margin in the setup window), and a
  fallback if GPS is degraded or jammed.
- **C-DAC VEGA.** The free RISC-V dev kits run the payload-release controller and
  failsafe watchdog — real Indian silicon flying, on a subsystem with a hardware
  bypass, off the flight-critical path.

Four things have no Indian option and are declared as such: AI inference silicon
(~20 TOPS class), high-drain 21700 cells at 45 A, 802.11/LoRa RF chipsets, and
high-current connectors.

Suppliers: Bharath Components · Mechtex · Flameback Tech · S R Aerospace · Agam
Robotics · Zuppa · Teravolt Labs · Accord Software · e-con Systems · FxUAV
Technologies · Kineco · Sundram Fasteners. Full BOM in
[`../hardware/bom/`](../hardware/bom/).

---

## Safety and failsafes

| Failsafe | Response |
|---|---|
| Low battery | Abort current task, return to home, sequenced landing |
| C2 link loss | Continue assigned bundle autonomously; RTH at 60 s |
| Mesh partition | Deterministic tie-break (lowest system ID); no task left unclaimed |
| Geofence breach | Immediate hold, then return to home |
| GPS degradation | Hold, climb for reacquisition, RTH on timeout |
| Payload jam | Flag the task for reallocation; continue mission |
| Mission abort | All aircraft hold, then sequenced recovery |
| Emergency recall | Immediate RTH on the 868 MHz link |

Deconfliction is layered: altitude stratification during search, exclusive
spatial locks around each survivor during delivery, reciprocal velocity-obstacle
avoidance as a runtime backstop, and strictly sequenced launch and recovery
through the 3.66 m box.

**Payload release requires a positive mechanical lock independent of servo
power.** A brownout must not drop a kit.

Vortex ring state is a live hazard on every delivery — the descent to 6 m is
near-vertical with nulled groundspeed, which is exactly the condition VRS needs.
See [`sizing/configuration-trade.md`](sizing/configuration-trade.md) §5.1.

---

## Technologies

**Flight** — ArduPilot / PX4 · MAVLink 2 · C-DAC VEGA (RISC-V)
**Autonomy** — ROS 2 · Fast DDS · DARP · CBBA
**Perception** — YOLO-class detector · TensorRT · SAHI tiling · OpenCV calibration
**Communication** — batman-adv mesh · 5.8 GHz + 868 MHz dual-band · mavlink-router
**Navigation** — NavIC (L1 + L5) · RTK · dual-antenna heading
**Ground** — React · offline ISRO Bhuvan tiles · mission replay
**Simulation** — Gazebo · multi-instance SITL · Monte Carlo + fault injection

---

## Working rules

- No new autonomy code touches a real airframe until it has run 20 consecutive
  clean SITL missions. SITL cycles cost minutes; a crash costs weeks.
- Every real flight runs a tagged commit, logged in the flight log with the tag.
- If a document disagrees with `docs/sizing/model-output.txt`, re-run the model
  and fix the document — not the reverse.

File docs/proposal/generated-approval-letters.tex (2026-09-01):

%============================================================================
% GENERATED FILE -- do not edit.
% Produced by tools/proposal/build_approval_letters.py from
% hardware/bom/sourced_bom.py. Edit the BOM, not this file.
%============================================================================

\clearpage
\thispagestyle{empty}
\begingroup
\footnotesize
\setlength{\parskip}{0.26em}
% The brief sets loose table spacing for readability; a letter has to fit one
% page, so it is reset here rather than globally.
\setlength{\extrarowheight}{0pt}
\renewcommand{\arraystretch}{1.02}

% ---- letterhead, matching the brief's ---------------------------------------
\noindent
\raisebox{-0.5\height}{}%
\hfill
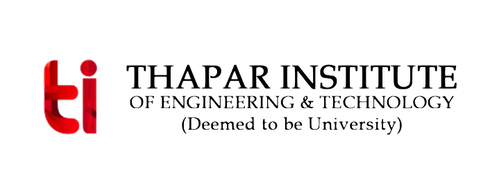
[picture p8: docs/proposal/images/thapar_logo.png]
\raisebox{-0.5\height}{}

\vspace{2mm}\hrule\vspace{2.5mm}

\begin{center}
{\small\bfseries RescueSwarm --- An Autonomous Multi-UAV System for Post-Disaster Search, Localisation and Payload Delivery}
\end{center}

\vspace{1mm}\hrule\vspace{2.5mm}

\noindent\begin{minipage}[t]{0.62\textwidth}
To\\
The Dean, Student Affairs (DoSA)\\
\emph{Through:} President, Thapar Amateur Astronomers Society (TAAS)\\
Thapar Institute of Engineering \& Technology, Patiala
\end{minipage}\hfill
\begin{minipage}[t]{0.34\textwidth}
\raggedleft
Ref.: RS/PH-1\\[2.2mm]
Date: \rule{28mm}{0.4pt}
\end{minipage}

\vspace{1mm}
\noindent\textbf{Subject:} Fund Request under TAAS Society for the RescueSwarm
Project --- Phase 1 of 30, Establish thrust and mass measurement capability

\noindent Respected Ma'am,

We, a team of students of Thapar Institute of Engineering \& Technology, are
working under the guidance of Dr. Surbhi Sharma and Dr. Mamata Gulati on \textbf{RescueSwarm}, an
autonomous multi-UAV system for post-disaster search, survivor localisation and
payload delivery. The software and simulation framework is complete, and the
programme is now in hardware integration and testing, funded in 30 steps so
that each is approved only once the previous has produced a stated result.

\noindent\textbf{This request is Phase 1 of 30: Establish thrust and mass measurement capability.} This is the first step, and is gated only on this approval.
We request funding for the following components:

\noindent\makebox[\textwidth][c]{%
\scriptsize
\begin{tabular}{@{}>{\raggedright\arraybackslash}p{3.1cm}>{\raggedright\arraybackslash}p{6.9cm}rr@{}}
\toprule
\textbf{Component} & \textbf{Model} & \textbf{Qty} & \textbf{Cost (INR)} \\
\midrule
Fasteners & Hex socket-head assortment M3/M4/M5, SS304 & 1 & 1{,}140 \\
Load cell & REES52 20 kg load cell + HX711 breakout & 1 & 854 \\
Threadlocker & Loctite 243, 50 ml & 1 & 664 \\
Thrust-stand mast & SURYAKUSH metal 2.1 m tripod & 1 & 373 \\
Load-cell amplifier & 7Semi HX711 24-bit ADC & 1 & 104 \\
\midrule
\multicolumn{3}{@{}r}{\textbf{Total}} & \textbf{3{,}135} \\
\bottomrule
\end{tabular}}

\noindent We kindly request approval and financial support of
\textbf{\rs{3{,}135}} under TAAS Society for the procurement of the components
above. This is the parts cost of this phase; the programme schedule additionally
carries tax where it is still owed, and a 15\,\% contingency.

\noindent\textbf{Team Members}\quad\emph{Mentors:} Dr. Surbhi Sharma and Dr. Mamata Gulati

\noindent\makebox[\textwidth][c]{%
\scriptsize
\begin{tabular}{@{}>{\raggedright\arraybackslash}p{3.0cm}>{\raggedright\arraybackslash}p{6.1cm}ll@{}}
\toprule
\textbf{Name} & \textbf{Department} & \textbf{Batch} & \textbf{Roll No.} \\
\midrule
Swastik Kumar & Electronics \& Communication Engineering & 2024--2028 & 1024060150 \\
Samuel Masih & Computer Science \& Engineering & 2024--2028 & 1024170044 \\
Prabhjot Singh & Robotics and Artificial Intelligence Engg. & 2024--2028 & 1024230021 \\
Manan Kapoor & Computer Science \& Engineering & 2024--2028 & 1024030467 \\
Manav Pansari & Electronics \& Communication Engineering & 2024--2028 & 1024060151 \\
Ravi Kant Raja & Robotics and Artificial Intelligence Engg. & 2024--2028 & 1024230032 \\
Neil Kishore & Mechanical Engineering & 2024--2028 & 1024080017 \\
\bottomrule
\end{tabular}}

\vspace{1.5mm}
\noindent\textbf{Approvals \& Signatures}

\vspace{8mm}
\noindent
\begin{tabular}{@{}p{5.3cm}p{5.3cm}p{5.4cm}@{}}
\hrulefill & \hrulefill & \hrulefill \\
\textbf{Dr. Surbhi Sharma} & \textbf{Dr. Mamata Gulati} & \textbf{President, TAAS} \\
{\footnotesize Mentor} & {\footnotesize Mentor} &
{\footnotesize Thapar Amateur Astronomers Society} \\
\end{tabular}

\vspace{5.5mm}
\noindent
\begin{tabular}{@{}p{8.2cm}p{8.2cm}@{}}
\hrulefill & \hrulefill \\
\textbf{Swastik Kumar} & \textbf{Date} \\
{\footnotesize Department of Electronics \& Communication Engineering, Roll No. 1024060150} & \\
{\footnotesize Submitted on behalf of the team} & \\
\end{tabular}

\vspace{2.5mm}
\noindent \fbox{\begin{minipage}{0.968\textwidth}
\vspace{0.8mm}
{\footnotesize \textbf{For office use --- Office of the Dean, Student Affairs}}

\vspace{6mm}
\begin{tabular}{@{}p{4.6cm}p{5.5cm}p{5.3cm}@{}}
\hrulefill & \hrulefill & \hrulefill \\
{\footnotesize Amount sanctioned (INR)} & {\footnotesize Signature} &
{\footnotesize Date} \\
\end{tabular}
\vspace{0.8mm}
\end{minipage}}
\endgroup

\clearpage
\thispagestyle{empty}
\begingroup
\footnotesize
\setlength{\parskip}{0.26em}
% The brief sets loose table spacing for readability; a letter has to fit one
% page, so it is reset here rather than globally.
\setlength{\extrarowheight}{0pt}
\renewcommand{\arraystretch}{1.02}

% ---- letterhead, matching the brief's ---------------------------------------
\noindent
\raisebox{-0.5\height}{}%
\hfill
\raisebox{-0.5\height}{}

\vspace{2mm}\hrule\vspace{2.5mm}

\begin{center}
{\small\bfseries RescueSwarm --- An Autonomous Multi-UAV System for Post-Disaster Search, Localisation and Payload Delivery}
\end{center}

\vspace{1mm}\hrule\vspace{2.5mm}

\noindent\begin{minipage}[t]{0.62\textwidth}
To\\
The Dean, Student Affairs (DoSA)\\
\emph{Through:} President, Thapar Amateur Astronomers Society (TAAS)\\
Thapar Institute of Engineering \& Technology, Patiala
\end{minipage}\hfill
\begin{minipage}[t]{0.34\textwidth}
\raggedleft
Ref.: RS/PH-2\\[2.2mm]
Date: \rule{28mm}{0.4pt}
\end{minipage}

\vspace{1mm}
\noindent\textbf{Subject:} Fund Request under TAAS Society for the RescueSwarm
Project --- Phase 2 of 30, Confirm one motor lifts what the design needs

\noindent Respected Ma'am,

We, a team of students of Thapar Institute of Engineering \& Technology, are
working under the guidance of Dr. Surbhi Sharma and Dr. Mamata Gulati on \textbf{RescueSwarm}, an
autonomous multi-UAV system for post-disaster search, survivor localisation and
payload delivery. The software and simulation framework is complete, and the
programme is now in hardware integration and testing, funded in 30 steps so
that each is approved only once the previous has produced a stated result.

\noindent\textbf{This request is Phase 2 of 30: Confirm one motor lifts what the design needs.} It falls due only once the previous step has produced its stated result: \emph{instruments commissioned}.
We request funding for the following components:

\noindent\makebox[\textwidth][c]{%
\scriptsize
\begin{tabular}{@{}>{\raggedright\arraybackslash}p{3.1cm}>{\raggedright\arraybackslash}p{6.9cm}rr@{}}
\toprule
\textbf{Component} & \textbf{Model} & \textbf{Qty} & \textbf{Cost (INR)} \\
\midrule
Motors & Tarot TL96020, 5008, 340 KV & 1 & 4{,}703 \\
\midrule
\multicolumn{3}{@{}r}{\textbf{Total}} & \textbf{4{,}703} \\
\bottomrule
\end{tabular}}

\noindent We kindly request approval and financial support of
\textbf{\rs{4{,}703}} under TAAS Society for the procurement of the components
above. This is the parts cost of this phase; the programme schedule additionally
carries tax where it is still owed, and a 15\,\% contingency.

\noindent\textbf{Team Members}\quad\emph{Mentors:} Dr. Surbhi Sharma and Dr. Mamata Gulati

\noindent\makebox[\textwidth][c]{%
\scriptsize
\begin{tabular}{@{}>{\raggedright\arraybackslash}p{3.0cm}>{\raggedright\arraybackslash}p{6.1cm}ll@{}}
\toprule
\textbf{Name} & \textbf{Department} & \textbf{Batch} & \textbf{Roll No.} \\
\midrule
Swastik Kumar & Electronics \& Communication Engineering & 2024--2028 & 1024060150 \\
Samuel Masih & Computer Science \& Engineering & 2024--2028 & 1024170044 \\
Prabhjot Singh & Robotics and Artificial Intelligence Engg. & 2024--2028 & 1024230021 \\
Manan Kapoor & Computer Science \& Engineering & 2024--2028 & 1024030467 \\
Manav Pansari & Electronics \& Communication Engineering & 2024--2028 & 1024060151 \\
Ravi Kant Raja & Robotics and Artificial Intelligence Engg. & 2024--2028 & 1024230032 \\
Neil Kishore & Mechanical Engineering & 2024--2028 & 1024080017 \\
\bottomrule
\end{tabular}}

\vspace{1.5mm}
\noindent\textbf{Approvals \& Signatures}

\vspace{8mm}
\noindent
\begin{tabular}{@{}p{5.3cm}p{5.3cm}p{5.4cm}@{}}
\hrulefill & \hrulefill & \hrulefill \\
\textbf{Dr. Surbhi Sharma} & \textbf{Dr. Mamata Gulati} & \textbf{President, TAAS} \\
{\footnotesize Mentor} & {\footnotesize Mentor} &
{\footnotesize Thapar Amateur Astronomers Society} \\
\end{tabular}

\vspace{5.5mm}
\noindent
\begin{tabular}{@{}p{8.2cm}p{8.2cm}@{}}
\hrulefill & \hrulefill \\
\textbf{Swastik Kumar} & \textbf{Date} \\
{\footnotesize Department of Electronics \& Communication Engineering, Roll No. 1024060150} & \\
{\footnotesize Submitted on behalf of the team} & \\
\end{tabular}

\vspace{2.5mm}
\noindent \fbox{\begin{minipage}{0.968\textwidth}
\vspace{0.8mm}
{\footnotesize \textbf{For office use --- Office of the Dean, Student Affairs}}

\vspace{6mm}
\begin{tabular}{@{}p{4.6cm}p{5.5cm}p{5.3cm}@{}}
\hrulefill & \hrulefill & \hrulefill \\
{\footnotesize Amount sanctioned (INR)} & {\footnotesize Signature} &
{\footnotesize Date} \\
\end{tabular}
\vspace{0.8mm}
\end{minipage}}
\endgroup

\clearpage
\thispagestyle{empty}
\begingroup
\footnotesize
\setlength{\parskip}{0.26em}
% The brief sets loose table spacing for readability; a letter has to fit one
% page, so it is reset here rather than globally.
\setlength{\extrarowheight}{0pt}
\renewcommand{\arraystretch}{1.02}

% ---- letterhead, matching the brief's ---------------------------------------
\noindent
\raisebox{-0.5\height}{}%
\hfill
\raisebox{-0.5\height}{}

\vspace{2mm}\hrule\vspace{2.5mm}

\begin{center}
{\small\bfseries RescueSwarm --- An Autonomous Multi-UAV System for Post-Disaster Search, Localisation and Payload Delivery}
\end{center}

\vspace{1mm}\hrule\vspace{2.5mm}

\noindent\begin{minipage}[t]{0.62\textwidth}
To\\
The Dean, Student Affairs (DoSA)\\
\emph{Through:} President, Thapar Amateur Astronomers Society (TAAS)\\
Thapar Institute of Engineering \& Technology, Patiala
\end{minipage}\hfill
\begin{minipage}[t]{0.34\textwidth}
\raggedleft
Ref.: RS/PH-3\\[2.2mm]
Date: \rule{28mm}{0.4pt}
\end{minipage}

\vspace{1mm}
\noindent\textbf{Subject:} Fund Request under TAAS Society for the RescueSwarm
Project --- Phase 3 of 30, Aircraft 1 -- autopilot and control link

\noindent Respected Ma'am,
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

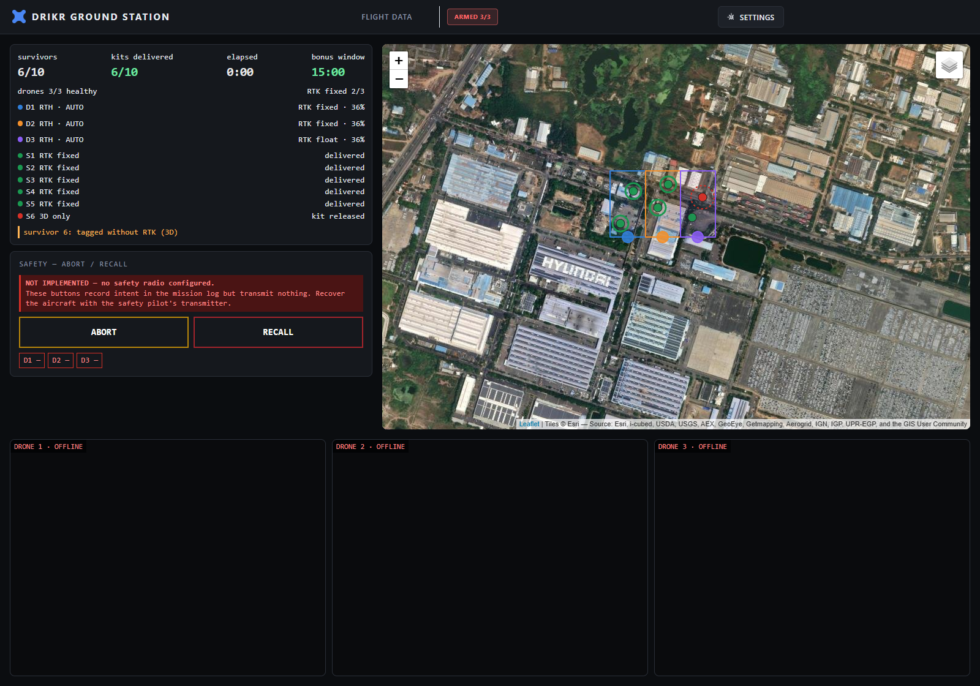
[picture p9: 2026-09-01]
ground-station/gcs-dark.png

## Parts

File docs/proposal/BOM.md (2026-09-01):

# RescueSwarm — Bill of Materials

Generated by `tools/proposal/build_bom.py` from the budget model. Do not
hand-edit: prices come from `docs/proposal/figures/competition_budget.py`
and the parts total is asserted against it.

**Link status.** `verified` — page opened and confirmed. `product` — a
page for this exact part is linked, but Robu.in returns 403 to automated
fetches, so the price was not read back from it; treat the INR column as
the budget figure, not a quoted price.
`supplier` — supplier known and named, exact page not confirmed.
`quote` — priced by quotation, no public listing. `fabricate` — made
in-house or locally. Links are never invented to fill the column.

| Phase | Item | Model | Unit INR | Qty | Line INR | Link | Link status |
|---|---|---|---|---|---|---|---|
| 3, 13, 21 | Flight controller | Holybro Pixhawk 6C Mini | 22,600 | 3 | 67,800 | [robu.in](https://robu.in/product/holybro-pixhawk-6c-mini-flight-controller/) | product |
| 4, 14, 22 | Companion computer | Raspberry Pi 5, 8 GB | 19,999 | 3 | 59,997 | Robu.in / Silverline / Element14 India | supplier |
| 4, 14, 22 | AI accelerator | Raspberry Pi AI HAT+, 26 TOPS (Hailo-8) | 11,000 | 3 | 33,000 | Robu.in / Silverline; multiple Indian retailers | supplier |
| 5, 15, 23 | GNSS RTK primary | Teravolt AeroNav-Pro RTK (or AeroNav-X5) | 25,000 | 3 | 75,000 | [teravolt.gitbook.io](https://teravolt.gitbook.io/teravolt/gps/aeronav-pro-rtk) | quote |
| 2, 10, 20, 28 | Motors | Tarot TL96020, 5008, 340 KV | 4,500 | 12 | 54,000 | Robokits India / IndiaMART | supplier |
| 8, 18, 26 | Li-ion cells | Molicel P45B 21700, 4500 mAh, 45 A | 700 | 54 | 37,800 | Robokits India (imported listing) | supplier |
| 7, 17, 25 | Structure | 25 x 23 mm carbon tube, machined clamps | 13,000 | 3 | 39,000 | in-house / local machine shop | fabricate |
| 6, 16, 24 | Camera + lens | Arducam 12.3 MP IMX477, 1/2.3 in, 6 mm CS mount, fixed focus | 11,100 | 3 | 33,300 | [robu.in](https://robu.in/product/arducam-hq-camera-for-jetson-nano-and-xavier-nx-12-3mp-1-2-3-inch-imx477-with-6mm-cs-mount-lens/) | product |
| 8, 18, 26 | Pack, BMS, PDB, BEC | 6S 60 A BMS, distribution board, regulator | 8,500 | 3 | 25,500 | Robu.in / IndiaMART | supplier |
| 6, 16, 24 | RC rx, storage, cooling, mounts | ExpressLRS 2.4 GHz receiver, storage, cooling, mounts | 8,500 | 3 | 25,500 | Robu.in / IndiaMART | supplier |
| 9, 19, 27 | ESCs | 50-60 A continuous, 6S | 1,800 | 12 | 21,600 | Robokits India / Robu.in | supplier |
| 6, 16, 24 | Video and coordination radios | 3x analog 5.8 GHz VTX, 3x GCS receiver + patch, 4x SX1262 865 MHz | 6,000 | 3 | 18,000 | supplier quotation | quote |
| 9, 19, 27 | Payload system | Four metal-gear servos, mechanical detents | 4,500 | 3 | 13,500 | Robu.in / Robokits India | supplier |
| 9, 19, 27 | Propellers | Tarot 1855 carbon, 18 in, CW/CCW | 1,625 | 12 | 19,500 | Robokits India | supplier |
| 9, 19, 27 | Wiring, connectors | 10 AWG silicone, XT90-S, JST-GH | 2,400 | 3 | 7,200 | Robu.in / IndiaMART | supplier |
| 9, 19, 27 | Prop adapters | 4 mm bore self-tightening hubs (Tarot TL96020 shaft is 4 mm) | 350 | 12 | 4,200 | Robokits India / Robu.in | supplier |
| 9, 19, 27 | VEGA co-processor | VEGA RISC-V development kit (no cost line) | 0 | 3 | 0 | C-DAC VEGA processor programme | supplier |
| 29 | RTK base receiver | Second Teravolt AeroNav unit, base station | 25,000 | 1 | 25,000 | [teravolt.gitbook.io](https://teravolt.gitbook.io/teravolt/gps/aeronav-x5) | quote |
| 30 | Survey tripod + tribrach | Photographic tripod and adapter | 4,000 | 1 | 4,000 | IndiaMART / local survey supplier | supplier |
| 11 | Safety-pilot transmitter | RadioMaster Boxer, ExpressLRS | 8,000 | 1 | 8,000 | IndiaMART / Robu.in | supplier |
| 12 | Sun hood + observer monitor | Fabricated hood, second-hand monitor | 1,500 | 1 | 1,500 | fabricated; monitor sourced locally | fabricate |
| 31 | Remaining ground items | Cables, mounts, spares, transport protection | 25,000 | 1 | 25,000 | local / Robu.in | supplier |
| 1 | Thrust stand | 20 kg load cell, HX711, power meter, in-house frame | 8,000 | 1 | 8,000 | load cell and HX711 from Robu.in; frame fabricated | fabricate |
| 11 | Battery chargers | ToolkitRC M6D, 500 W, 25 A, dual | 14,000 | 1 | 14,000 | Indian Hobby Center / Robu.in | supplier |
| 1 | Calibrated scale + remaining | Bench scale, 30 kg, 1 g, certified | 12,000 | 1 | 12,000 | IndiaMART (calibration certificate required) | supplier |
| 12 | Fasteners, tape, connectors, filament | Consumables | 13,000 | 1 | 13,000 | local / Robu.in | supplier |
| 32 | DGCA registration | Statutory fee, three aircraft | 5,000 | 1 | 5,000 | [digitalsky.dgca.gov.in](https://digitalsky.dgca.gov.in/) | verified |

**Parts total: INR 650,397**

Landed programme total, after 22% duty on the imported share, 18% GST and 15% contingency: **INR 827,788**

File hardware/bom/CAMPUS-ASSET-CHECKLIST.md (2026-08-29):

# Campus asset checklist

**Purpose.** Find out what the institute already owns, before asking it for
money. Every confirmed *yes* either reduces the request or removes a risk, and
none of it costs the project any capability — it is the same equipment,
borrowed instead of bought.

**How to use it.** Grouped by *where you go*, not by budget line, so each visit
is one conversation. Ask the question as written. The general question invites a
misleading answer: *"do you have a GPS?"* gets a yes that turns out to be a
total station.

**Record the answer, not just yes/no.** "Yes, but booked until March" is a no.
"Yes, but it can't leave the building" is a no for the weigh-in scale.

---

## Summary of what is at stake

| | Value | Effect if confirmed |
|---|--:|---|
| **A · Equipment we have budgeted** | **₹56,000** remaining | Leaves the request. Ask falls to ~₹6,66,000 |
| · *already confirmed 2026-08-18* | *₹14,500 done* | *ask 8,24,072 → **7,37,829** (with the deferrals below)* |
| **B · Stock and consumables** | up to ~₹15,000 | Partial reductions |
| **C · Questions that remove risk** | ₹25,000 + travel | Resolves the insurance flag |
| **D · Assets already assumed** | **₹3,54,000** | ✅ **all nine confirmed** — ask is safe |

> **D was as important as A, and it is now settled.** The budget assumes
> ₹3,54,000 of institute equipment is available to us. All nine items were
> confirmed on 2026-08-18, so none of that comes back into the request and the
> ₹7,37,829 figure holds.

---

## A · Equipment that would leave the budget — ₹56,000 remaining

> **Confirmed held 2026-08-18** and already removed from the request:
> equipment cases (₹9,000), lithium fire kit (₹4,000), charger PSU (₹1,500).
> A further review then deferred the remaining spares, the relief kits and
> the ground-truth apparatus. **The ask is now ₹7,37,829.** The items below
> are still open.

### → Civil Engineering, survey laboratory

**☐ RTK base receiver — ₹18,000 · biggest single item, least likely to just work**

> "Do you have a survey-grade GNSS receiver that can run as a **base station**
> and output **RTCM3 corrections** over serial or IP to a third-party rover, at
> about 1 Hz? And would it be free for roughly eight field days between
> [months]?"

- **Disqualifies:** a total station (not GNSS). A receiver that only post-processes
  and cannot stream live corrections. Anything booked for coursework in our window.
- Answer: ______________________________________________

**☐ Survey tripod + tribrach — ₹4,000**

> "A standard tripod with a 5/8‑inch thread and a tribrach we could borrow for
> field days?"

- Answer: ______________________________________________

---

### → Robotics / aeromodelling club

**☐ Safety-pilot transmitter — ₹8,000**

> "Do you have an **ExpressLRS** transmitter, or a radio with a **module bay**
> that can take an ELRS module?"

- **Disqualifies:** FlySky, Spektrum, or any non-ELRS set. It is the wrong
  protocol and cannot bind to our receivers. A module bay is enough — the module
  itself is cheap.
- Answer: ______________________________________________

**☐ Battery chargers — ₹14,000**

> "A charger that balance-charges **6S lithium at 5 A or more**, and measures
> **per-cell internal resistance**?"

- Internal-resistance measurement matters: it is why the separate cell tester was
  already deleted from the budget. If the charger cannot do it, say so.
- Answer: ______________________________________________

**☐ Spare propellers, ESCs, connectors** — see section B

---

### → Mechanical Engineering laboratory

**☐ Calibrated scale — ₹12,000**

> "A calibrated balance reading to about 1 g up to 10 kg — and **can it leave
> the building** for a competition day?"

- **Disqualifies:** a bench-bound balance. This decides the Rule C2 weigh-in, so
  it has to travel. If it cannot, we still need to buy one.
- Answer: ______________________________________________

**☐ Load cell and DAQ — would offset the ₹8,000 thrust stand**

> "Do you have a **load cell up to about 10 kg with a data-logger or DAQ** we
> could use for propeller thrust measurement?"

- The thrust stand is being fabricated, but the instrumentation is the expensive
  part. This one is **load-bearing for the project**: our motors publish no
  thrust curve, so this measurement decides whether the aircraft hovers.
- Answer: ______________________________________________

---

### → Departmental stores

**☑ Equipment cases — ₹9,000** · **CONFIRMED HELD, removed from the request**

- Answer: ______________________________________________

**☑ Charger PSU — ₹1,500** · **CONFIRMED HELD, removed from the request**

- Answer: ______________________________________________

---

### → Institute safety office

**☑ Fire extinguisher, sand, lithium charging bags — ₹4,000** · **CONFIRMED HELD**

> "A **CO₂ or Class D** extinguisher and lithium charging bags that can be
> **signed out to a field site**?"

- 54 lithium cells are cycled across this programme. Thermal runaway is a real
  failure mode, so this capability is kept whether or not it is borrowed.
- Answer: ______________________________________________

---

## B · Stock and consumables — up to ~₹15,000

These come out of the ₹13,000 fasteners line and the ₹21,400 stock line.
Partial answers still help.

**☐ 3D printer filament** — the institute already provides the printer. Does it
provide **PETG or ASA filament** too, or do we buy our own?

- Answer: ______________________________________________

**☐ Carbon-fibre offcuts** — does the machine shop hold **CF plate or tube
stock**, or offcuts from previous projects we could use for spares?

- Answer: ______________________________________________

**☐ Fasteners** — is there a **stores stock of M3 socket-cap, nyloc and
washers** we can draw against?

- Answer: ______________________________________________

---

## C · Questions that remove a risk rather than a cost

### → Dean R&D / accounts office

**☐ Insurance — resolves a ₹25,000 open item and a flight blocker**

> "Does the institute hold **third-party liability cover that extends to student
> projects operating unmanned aircraft**? If not, is it required before we fly?"

- This is currently the **single unresolved item in the budget**. Cover is
  commonly mandatory for unmanned operations in India. If the institute already
  holds a policy that extends to us, the ₹25,000 stays out and the flight
  blocker clears. If it does not, we need to know **before any flight**, not
  after.
- Answer: ______________________________________________

**☐ Travel and participation fund — money that is not in this budget at all**

> "Is there a **separate fund for competition travel, accommodation and entry
> fees**, distinct from equipment funding?"

- Our request covers **equipment only**. Getting three aircraft and a team to the
  venue is not costed anywhere. Many institutes fund this from a different head,
  which means it need not compete with the equipment request.
- Answer: ______________________________________________

**☐ Sanction thresholds and budget heads**

> "What are the **sanction limits**, and which **head** should capital equipment
> versus consumables be indented under?"

- We need this to submit correctly, not to structure around it. Our tranches are
  tied to technical milestones and must not be presented as a split indent.
- Answer: ______________________________________________

**☐ Flight-testing site**

> "Is there an approved **open area on or near campus** we may use for UAV flight
> testing, and what permission is needed?"

- Answer: ______________________________________________

---

## D · Confirm what the budget already assumes — ₹3,54,000

**✅ ALL NINE CONFIRMED AVAILABLE, 2026-08-18.** These are counted as
institutional contribution and removed from the request. Confirming them means
no money comes back into the ask — the ₹8,07,397 figure is safe.
Confirming them protects the figure being submitted.

| ☐ | Item | Assumed value | Confirmed available? |
|---|---|--:|---|
| ☐ | Training GPUs (model training) | ₹75,000 | ______________ |
| ☐ | Ground-station laptop | ₹85,000 | ______________ |
| ☐ | Backup ground-station laptop | ₹55,000 | ______________ |
| ☐ | Portable power station / field power | ₹55,000 | ______________ |
| ☐ | 3D printer | ₹50,000 | ______________ |
| ☐ | Soldering station | ₹9,000 | ______________ |
| ☐ | Rotary tool + CF extraction | ₹8,500 | ______________ |
| ☐ | Bench power supply | ₹8,500 | ______________ |
| ☐ | Multimeters | ₹8,000 | ______________ |
| | **Total assumed** | **₹3,54,000** | |

For the GPUs, the question that matters is not *"do you have GPUs"* but:

> "Can we get **scheduled access** to them for model training over [months],
> and roughly how many GPU-hours?"

---

## After the walk-around

1. Total the confirmed items in section A.
2. Regenerate the workbook with those lines zeroed, and re-check the covering
   note against tab 00 — the ask, the capital share and the institutional
   contribution all move together.
3. If anything in **D** came back unavailable, add it back to the request before
   submitting.
4. Open the covering note with what you found. *"We audited the institute's
   existing assets and reduced this request by ₹X before submitting it"* is a
   materially stronger opening than the same number without it.

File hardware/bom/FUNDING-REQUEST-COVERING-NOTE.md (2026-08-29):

# Covering note — institutional funding request

> **Before sending:** fill the seven bracketed fields — addressee, department,
> programme and year, date, institute, email, phone — then delete this block.
> Everything else is ready. The figures come from
> `RescueSwarm_University_Funding_Request.xlsx`; if you change the budget,
> regenerate the workbook and re-check the numbers here against tab 00.

---

To: **[Dean, Research & Development / Head of Department]**
From: **Swastik Kumar**, [Department], [Programme and year]
Date: **[Date]**
Subject: **Request for institutional funding — Project RescueSwarm, NIDAR 2026–27**

---

I am writing to request institutional funding of **₹7,37,829** for Project
RescueSwarm, our entry to NIDAR 2026–27 (Track 1): a three-aircraft autonomous
unmanned system for search-and-rescue, which locates casualties from the air and
delivers relief payloads to them without an operator flying the aircraft.

I want to make one point at the outset, because it changes what is being decided.

**This is not a request to spend ₹7.38 lakh. It is a request to acquire
₹6,83,306 of durable laboratory equipment and to spend ₹54,523.** Of the
total, **92.6% is capital that remains the institute's property** after the
competition ends — three flying UAV platforms, a centimetre-accurate RTK GNSS
base station, a calibrated propulsion thrust stand, and battery and field
equipment. These become a working UAV laboratory available to every subsequent
student project, thesis and competition entry. Only ₹54,523 — field cabling and
mounts, fasteners and consumables, and the DGCA registration fee — is genuinely
consumed. Tabs 03 and 04 itemise both, on a deliberately conservative test:
anything partly consumable is counted as consumed, so the retention figure holds
up if the accounts office challenges it.

**The institute already funds 33% of this programme.** Training GPUs, ground-
station laptops, the 3D printer, the machine shop and laboratory instruments are
already available to us and are costed into the programme at ₹3,68,500 — at no
new cost. Against a total programme value of ₹11,06,329, this request is
leverage on assets the institute already holds rather than a standalone expense.

**Funds are not required at once, and the first decision is ₹2,50,000.** The
request is structured as four tranches released against demonstrated technical
milestones: ground segment demonstrated and failure behaviour verified by fault
injection; three airframes weighed and first hover complete; perception and
delivery trials reported with measured figures. If the programme fails to
demonstrate a gate, the remaining funds are not released and the institute's
exposure is capped at one tranche. These are engineering milestones, not
administrative convenience, and I would ask that they be treated as a genuine
risk control rather than as a phased indent.

**We audited the institute's existing assets before asking, and it has already
reduced this request.** Equipment cases, the lithium fire kit and a charger PSU
were confirmed held on campus and have been removed. A further review then
deferred the remaining spares, the relief kits and the ground-truth apparatus.
Together these took the ask from ₹8,24,072 to ₹7,37,829. Tab 02 lists a further ₹56,000 of equipment — a precision balance, a survey tripod, LiPo chargers, an
RTK base receiver — that may already exist in Civil Engineering, the robotics
and aeromodelling clubs, or departmental stores. Each entry states the specific
property that decides whether the existing item is actually usable for this
project, because the general question invites a misleading answer. **If all are
available to borrow, this request falls to approximately ₹6,66,000** and the
institute's share of the programme rises further. I would welcome direction on
whom to approach.

I should also record what we chose **not** to request, because it is now the
larger half of the story. **₹3,74,000 of capability has been deliberately
deferred** — a second GNSS receiver, recovery parachutes, a training airframe, a
third radio link, and **the entire spares provision** — each listed in tab 07
with its reasoning. The budget was reduced from an initial ₹28,74,000 programme
costing to ₹7,37,829, a 74% reduction, by removing everything the competition
entry does not strictly require. The team has accepted that a single crash or
propeller strike would now end the flight-test campaign, since no airframe,
propeller, motor or battery spares are carried.

**One item needs the institute's judgement rather than mine.** Third-party
flight insurance (₹25,000) is currently deferred. Cover is commonly mandatory
for unmanned aircraft operations in India, and I have not been able to confirm
whether it is required here. It must be settled against the DGCA Drone Rules and
the competition rulebook **before any flight takes place**. If it is required,
it ceases to be a budget choice and this amount returns to the request. I raise
it now rather than discover it later.

The attached workbook contains the full bill of materials with Indian
suppliers, the capital and consumable classification, the release schedule, the
deferred items, and a statement of how every figure was produced. The supporting
technical proposal is available on request. I would be glad to present this to
the committee and to answer questions on any figure in it.

With thanks,

**Swastik Kumar**
[Department], [Institute]
[Email] · [Phone]

---

### Attachments

1. `RescueSwarm_University_Funding_Request.xlsx` — funding request, 9 tabs
2. `rescueswarm-proposal.pdf` — technical proposal *(optional; on request)*

### Figures at a glance

| | ₹ |
|---|--:|
| **Requested** | **7,37,829** |
| — capital retained by the institute (92.6%) | 6,83,306 |
| — genuinely consumed (7.4%) | 54,523 |
| Already provided by the institute | 3,68,500 |
| Total programme value | 11,06,329 |
| First tranche only | 2,50,000 |
| Further reduction if the remaining assets are available | −56,000 |
| Deliberately deferred | 3,74,000 |

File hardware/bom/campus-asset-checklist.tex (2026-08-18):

% Campus asset checklist -- printable walk-around sheet.
% Build:  pdflatex campus-asset-checklist.tex
\documentclass[10pt,a4paper]{article}
\usepackage[margin=15mm,top=14mm,bottom=14mm]{geometry}
\usepackage{amssymb}
\usepackage{xcolor}
\usepackage{booktabs}
\usepackage{array}

\definecolor{ink}{HTML}{111111}
\definecolor{dim}{HTML}{5A5A62}
\definecolor{rule}{HTML}{C9C9CF}
\definecolor{hi}{HTML}{0B5394}
\definecolor{warn}{HTML}{9C0006}
\definecolor{band}{HTML}{EEF1F6}

\setlength{\parindent}{0pt}
\pagestyle{empty}
\renewcommand{\arraystretch}{1.35}

% a real tick box, and a write-on rule
\newcommand{\tick}{\raisebox{-0.8pt}{\framebox[3.0mm]{\rule{0pt}{3.0mm}}}}
\newcommand{\rs}[1]{Rs.~#1}
\newcommand{\writeline}{\textcolor{rule}{\leaders\hrule height 0.4pt\hfill\kern0pt}}

% section heading with a coloured band
\newcommand{\where}[1]{%
  \vspace{3.2mm}%
  \colorbox{band}{\parbox{\dimexpr\linewidth-2\fboxsep}{%
    \vspace{0.6mm}\textbf{\small #1}\vspace{0.6mm}}}%
  \vspace{1.6mm}%
}
\newcommand{\bigsec}[1]{%
  \vspace{3.5mm}{\color{hi}\rule{\linewidth}{0.9pt}}\\[1.2mm]
  {\bfseries\large #1}\\[0.6mm]
}
% one checklist item: box, name, value
\newcommand{\entry}[2]{\tick~\textbf{#1}\hfill\textcolor{dim}{\small #2}\\[0.8mm]}
\newcommand{\ask}[1]{\begin{quote}\vspace{-2mm}\itshape #1\vspace{-2mm}\end{quote}}
\newcommand{\nope}[1]{{\small\textcolor{warn}{\textbf{Not a match if:}} #1}\\[1.0mm]}
\newcommand{\ansline}{\textcolor{dim}{\footnotesize Answer:}~\writeline\\[2.2mm]}

\begin{document}

{\LARGE\bfseries Campus asset checklist}\\[1.5mm]
{\color{dim}Project RescueSwarm · NIDAR 2026--27 · what to confirm before
submitting the funding request}\\[1mm]
{\color{rule}\rule{\linewidth}{1.2pt}}\\[2.5mm]

\textbf{Why.} Find out what the institute already owns \emph{before} asking it
for money. Every confirmed \emph{yes} either reduces the request or removes a
risk, and none of it costs the project any capability --- it is the same
equipment, borrowed instead of bought.

\vspace{1.5mm}
\textbf{How.} Grouped by \emph{where you go}, so each visit is one
conversation. \textbf{Ask the question as written.} The general question invites
a misleading answer: \emph{``do you have a GPS?''} gets a yes that turns out to
be a total station. Record the answer, not just yes/no --- ``yes, but booked
until March'' is a no.

\vspace{2.5mm}
\begin{center}
\begin{tabular}{@{}p{58mm}r p{78mm}@{}}
\toprule
\textbf{Section} & \textbf{Value} & \textbf{Effect if confirmed}\\
\midrule
A · Budgeted equipment      & \rs{70,500}   & Leaves the request. Ask falls to about \rs{7,43,000}\\
B · Stock and consumables   & $\sim$\rs{15,000} & Partial reductions\\
C · Questions that remove risk & \rs{25,000}+ & Resolves the insurance blocker\\
\textbf{D · Already assumed} & \textbf{\rs{3,54,000}} & \textbf{Confirm, or the ask goes UP}\\
\bottomrule
\end{tabular}
\end{center}

\vspace{1mm}
{\small\textcolor{warn}{\textbf{Section D matters as much as section A.}} The
budget already assumes \rs{3,54,000} of institute equipment is available to us.
If it is not, that money comes back into the request. Confirming it protects the
number you are submitting.}

\bigsec{A · Equipment that would leave the budget --- \rs{70,500}}

\where{$\rightarrow$ Civil Engineering, survey laboratory}

\entry{RTK base receiver}{\rs{18,000} · biggest single item, least likely to just work}
\ask{``Do you have a survey-grade GNSS receiver that can run as a \textbf{base
station} and output \textbf{RTCM3 corrections} over serial or IP to a
third-party rover, at about 1\,Hz? Would it be free for roughly eight field
days?''}
\nope{it is a total station (not GNSS); it only post-processes and cannot
stream live corrections; it is booked for coursework in our window.}
\ansline

\entry{Survey tripod + tribrach}{\rs{4,000}}
\ask{``A standard tripod with a 5/8-inch thread and a tribrach we could borrow
for field days?''}
\ansline

\where{$\rightarrow$ Robotics / aeromodelling club}

\entry{Safety-pilot transmitter}{\rs{8,000}}
\ask{``Do you have an \textbf{ExpressLRS} transmitter, or a radio with a
\textbf{module bay} that can take an ELRS module?''}
\nope{it is FlySky, Spektrum or any non-ELRS set --- wrong protocol, cannot
bind to our receivers. A module bay alone is enough; the module is cheap.}
\ansline

\entry{Battery chargers}{\rs{14,000}}
\ask{``A charger that balance-charges \textbf{6S lithium at 5\,A or more}, and
measures \textbf{per-cell internal resistance}?''}
\nope{it cannot measure internal resistance --- that capability is why the
separate cell tester was already deleted from the budget.}
\ansline

\where{$\rightarrow$ Mechanical Engineering laboratory}

\entry{Calibrated scale}{\rs{12,000}}
\ask{``A calibrated balance reading to about 1\,g up to 10\,kg --- and
\textbf{can it leave the building} for a competition day?''}
\nope{it is bench-bound. This decides the Rule C2 weigh-in, so it has to
travel. If it cannot, we still buy one.}
\ansline

\entry{Load cell and DAQ}{would offset the \rs{8,000} thrust stand}
\ask{``Do you have a \textbf{load cell up to about 10\,kg with a data-logger or
DAQ} we could use for propeller thrust measurement?''}
{\small This one is \textbf{load-bearing for the project}: our motors publish no
thrust curve, so this measurement decides whether the aircraft hovers.}\\[1.2mm]
\ansline

\where{$\rightarrow$ Departmental stores}

\entry{Equipment cases}{\rs{9,000} · foam-lined, must survive transport to the venue}
\ansline
\entry{Charger PSU}{\rs{1,500} · 12\,V at 20\,A or better, usable in the field}
\ansline

\where{$\rightarrow$ Institute safety office}

\entry{Fire extinguisher, sand, lithium charging bags}{\rs{4,000}}
\ask{``A \textbf{CO$_2$ or Class D} extinguisher and lithium charging bags that
can be \textbf{signed out to a field site}?''}
{\small 54 lithium cells are cycled across this programme. Thermal runaway is a
real failure mode, so this capability is kept whether or not it is
borrowed.}\\[1.2mm]
\ansline

\newpage

\bigsec{B · Stock and consumables --- up to about \rs{15,000}}

{\small Drawn from the \rs{13,000} fasteners line and the \rs{21,400} stock
line. Partial answers still help.}\\[2mm]

\entry{3D printer filament}{the institute already provides the printer}
\ask{``Does the department supply \textbf{PETG or ASA filament}, or do we buy
our own?''}
\ansline

\entry{Carbon-fibre offcuts}{machine shop}
\ask{``Do you hold \textbf{CF plate or tube stock}, or offcuts from previous
projects we could use for spares?''}
\ansline

\entry{Fasteners}{stores}
\ask{``Is there a stock of \textbf{M3 socket-cap, nyloc and washers} we can draw
against?''}
\ansline

\bigsec{C · Questions that remove a risk rather than a cost}

\where{$\rightarrow$ Dean R\&D / accounts office}

\entry{Insurance}{resolves a \rs{25,000} open item \emph{and} a flight blocker}
\ask{``Does the institute hold \textbf{third-party liability cover that extends
to student projects operating unmanned aircraft}? If not, is it required before
we fly?''}
{\small\textcolor{warn}{This is the single unresolved item in the budget.}
Cover is commonly mandatory for unmanned operations in India. If the institute
already holds a policy that extends to us, the \rs{25,000} stays out and the
flight blocker clears. If it does not, we must know \textbf{before any flight},
not after.}\\[1.2mm]
\ansline

\entry{Travel and participation fund}{money that is not in this budget at all}
\ask{``Is there a \textbf{separate fund for competition travel, accommodation
and entry fees}, distinct from equipment funding?''}
{\small Our request covers \textbf{equipment only}. Getting three aircraft and a
team to the venue is costed nowhere. Many institutes fund this from a different
head, so it need not compete with the equipment request.}\\[1.2mm]
\ansline

\entry{Sanction thresholds and budget heads}{}
\ask{``What are the \textbf{sanction limits}, and which \textbf{head} should
capital equipment versus consumables be indented under?''}
{\small We need this to submit correctly, not to structure around it. Our
tranches are tied to technical milestones and must not be presented as a split
indent.}\\[1.2mm]
\ansline

\entry{Flight-testing site}{}
\ask{``Is there an approved \textbf{open area on or near campus} we may use for
UAV flight testing, and what permission is needed?''}
\ansline

\bigsec{D · Confirm what the budget already assumes --- \rs{3,54,000}}

{\small These are already counted as institutional contribution and
\emph{removed} from the request. If any is not actually available, that money
comes back into the ask.}\\[2.5mm]

\begin{tabular}{@{}c p{74mm} r p{52mm}@{}}
\toprule
 & \textbf{Item} & \textbf{Assumed} & \textbf{Confirmed available?}\\
\midrule
\tick & Ground-station laptop            & \rs{85,000} & \writeline\\
\tick & Training GPUs (model training)   & \rs{75,000} & \writeline\\
\tick & Backup ground-station laptop     & \rs{55,000} & \writeline\\
\tick & Portable power station / field power & \rs{55,000} & \writeline\\
\tick & 3D printer                       & \rs{50,000} & \writeline\\
\tick & Soldering station                & \rs{9,000}  & \writeline\\
\tick & Rotary tool + CF extraction      & \rs{8,500}  & \writeline\\
\tick & Bench power supply               & \rs{8,500}  & \writeline\\
\tick & Multimeters                      & \rs{8,000}  & \writeline\\
\midrule
 & \textbf{Total assumed} & \textbf{\rs{3,54,000}} & \\
\bottomrule
\end{tabular}

\vspace{3mm}
For the GPUs the question that matters is not \emph{``do you have GPUs''} but:
\ask{``Can we get \textbf{scheduled access} for model training, and roughly how
many GPU-hours?''}

\bigsec{After the walk-around}

\begin{tabular}{@{}r@{\hspace{2.5mm}}p{158mm}@{}}
1. & Total the confirmed items in section A.\\
2. & Regenerate the workbook with those lines zeroed, then re-check the covering
     note against tab 00 --- the ask, the capital share and the institutional
     contribution all move together.\\
3. & If anything in \textbf{D} came back unavailable, add it back to the request
     \emph{before} submitting.\\
4. & Open the covering note with what you found. ``We audited the institute's
     existing assets and reduced this request by \rs{X} before submitting it''
     is a materially stronger opening than the same number without it.\\
\end{tabular}

\vspace{4mm}
{\color{rule}\rule{\linewidth}{0.4pt}}\\[1mm]
{\footnotesize\color{dim}Generated from
\texttt{hardware/bom/campus-asset-checklist.tex}. Figures reconcile with
\texttt{RescueSwarm\_University\_Funding\_Request.xlsx} tab 02 and
\texttt{build\_university\_request.py}.}

\end{document}

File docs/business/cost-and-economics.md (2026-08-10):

# Cost and unit economics

**Business Strategy parameter 5 — "Expenditure Breakdown & Resource Planning",
20 points — and the numeric spine of parameters 3, 4 and 8.**

Every figure here is arithmetic over
[`hardware/bom/RescueSwarm_BOM_India.xlsx`](../../hardware/bom/RescueSwarm_BOM_India.xlsx),
generated by [`cost_model.py`](../../tools/sizing-model/cost_model.py) and
regenerated in CI. Change a supplier or a quantity and these move with it.

**Nothing here is a market claim.** §5 lists what the pitch still needs and
where it has to come from.

---

## 1. What the programme costs

| | INR |
|:--|--:|
| Air vehicle, **per aircraft** | 2.64 L |
| × 3 for the fleet | 7.93 L |
| Payload, ground segment, test equipment, spares, software | 11.02 L |
| **Subtotal** | **18.96 L** |
| Duty + freight, 22 % on the imported residual only | 1.34 L |
| GST, 18 % | 3.65 L |
| Contingency, 20 % | 4.79 L |
| **PROGRAMME TOTAL** | **28.74 L** |

**₹28.74 lakh is the funding ask.** Say plainly that it is a *competition build,
not a product*: it carries test and calibration equipment, a full spares set
including a spare airframe structure, and a field data campaign that a
production unit would not.

### Where it came down from ₹36.97 L

A cost pass on 2026-08-10 cut the subtotal 21 %. Worth being able to walk a
panel through, because "we took a fifth out and the aircraft did not change" is
a stronger answer than a low number on its own:

| Cut | INR | Why it was not a capability |
|:--|--:|:--|
| Dev workstation / GPU | 1.65 L | Duplicated the Indian GPU cloud line, which is cheaper **and** more indigenous (I1 0.9 vs I3 0.2). Cloud raised 0.40 → 0.75 L; net 1.30 L |
| Complete fourth aircraft → spare structure set | 1.40 L | Spares already held motors, ESCs, props, arms, FC, GNSS, compute, camera and three packs — ₹2.1 L. The fourth airframe bought most of it twice; what was missing was the structure |
| AI compute module, ×3 + spare | 0.68 L | Priced for an integrated edge-AI box; §8.2 sizes the mission on an Orin Nano-class module |
| GCS + backup laptop | 0.50 L | The load is 3 × H.264 decode and a Python GCS. With training on cloud, neither machine needs a discrete GPU |
| Power station 2 → 1.2 kWh | 0.25 L | 3 × 292 Wh at ~85 % efficiency is 1.03 kWh. The extra was reserve nothing asked for |
| Equipment cases, chargers, PSU, spot welder, solar panel, duplicate instruments | 0.62 L | Optional by the BOM's own note, or specified above the requirement, or bought in twos |
| **Total** | **5.10 L** | |

**No flight mass changed** — tab 01 bottom-up stays at 6,236 g, so MTOW,
endurance and the 25 kg margin are untouched. Nothing on the flight-critical
path was cut, and tab 08's DO-NOT-CUT list (safety equipment, the calibrated
scale, the spares that protect the flight window) is intact.

Cut lines sit at Qty 0 with their price still in the cell, so reinstating one is
a single-cell edit. **The one accepted risk is the fourth aircraft:** rebuilding
a crashed airframe now consumes the spares, so a second failure in the same week
is uncovered. Rule C1 needs only two aircraft flying. If funding arrives, this
is the first ₹1.65 L to spend.

## 2. What an additional system costs

The programme total is the wrong number to quote a customer, because most of it
is one-off. What scales is the marginal cost.

| | INR |
|:--|--:|
| Marginal aircraft, taxes in | 3.34 L |
| Three-aircraft fleet | 10.02 L |
| Ground segment, one per fleet | 4.58 L |
| **Deployable system, cost basis** | **14.60 L** |

**Cost basis, not price.** Margin, warranty, training, support and
certification are commercial decisions and are not BOM arithmetic. Do not let
the deck blur the two — a panel will ask.

## 3. Indigenisation, quantified

**67.9 % Indian content, value-weighted across the priced BOM** — up from 61.3 %,
because the cost pass cut two of the least-indigenous lines in the programme (an
assembled RTX workstation at I3 0.2, a second full-price laptop at I3 0.25) and
moved the work they were doing onto Indian GPU cloud at I1 0.9. Not a slogan —
every line carries a declared Indian fraction, so the number is auditable.

| | INR |
|:--|--:|
| Programme as costed | 28.74 L |
| The same BOM fully imported | 32.75 L |
| **Saved by sourcing in India** | **4.01 L — 12 %** |

The saving is real but it is the smaller half of the argument. **The bigger half
is schedule:** the BOM's own note puts imports at 4–6 weeks against 2–3 weeks
domestic, inside a programme whose binding constraint is an **8-week flight-test
window**. Indigenisation buys flying days, and flying days are what the 600
flight points are made of.

This matters to the audience specifically — MeitY and the Drone Federation of
India — and it is one of the few claims in the deck that is measured rather than
asserted.

## 4. Recurring cost

The consumable that matters is **kits, not energy**. A sortie is a pack cycle
and a few rupees of electricity: 292 Wh, 15.3 min hover endurance against a
7.7 min design mission. The fleet carries 3 × 4 = **12 kits per sortie**.

Three things are genuinely unknown and are not guessed here:

- **Kit refill cost** — the BOM buys competition kits, not relief kits
- **Battery cycle life** at this C-rate in Indian ambient
- **Crew and transport** per deployment

## 5. What the pitch still needs, and from where

These are the remaining numbers. Each is a question for the team, not a gap to
fill with a plausible figure.

| Need | Parameter | Where it has to come from |
|:--|:--|:--|
| How many flood-response units exist, and their refresh rate | 3 — Market Sizing (30) | NDRF/SDRF establishment data; state disaster authority procurement records |
| What a buyer actually pays for comparable capability | 4 — Business Model (30) | Published tenders — GeM, state DM authority tenders |
| Cost per flight hour of the helicopter or boat search this displaces | 3, 4 | Published SAR operating costs |
| Funds raised, sponsors | 6 — Funds Raised (20) | ⏳ **lead time — start now, cannot be produced in the final week** |
| Partner conversations | 8 — Go-to-Market (20) | ⏳ **lead time** |
| DGCA category, BVLOS status, procurement cycle | 9 — Regulatory (10) | DGCA UAS Rules; state procurement process |

**A pitch that derives its cost from a real BOM and states which numbers are
unsourced is stronger than one that is confident throughout — because the first
can be checked.** Panels test confidence; they reward traceability.

---

## 6. Defects found while building this

Recorded because they are the same failure mode the rest of this repository is
organised against, and because both produced *plausible* answers.

**Indigenisation first read as 0.0 %.** The column detector matched
`Indigenisation gap or action` — a prose column further right — instead of
`Indig. %`, because the loop kept overwriting on later matches. Zero percent is
a believable answer for a first draft, so it would very likely have shipped.
The model now refuses to run rather than report a zero it cannot justify.

**The BOM's own header still says `MTOW ~5.7 kg, fleet ~17 kg`.** The design
point is **6.36 kg / 19.08 kg**. It is descriptive text rather than a formula,
so nothing computed from it is wrong — but it is the third instance of a number
transcribed into prose and then left behind, and it is in the document that will
be handed to suppliers.

**Three more of the same, found by the cost pass moving the numbers.**
`cost_model.py` printed the label `programme as costed (61.3% Indian)` as a
string literal, next to the derived figure it was supposed to echo — so it kept
saying 61.3 % after the real number moved to 67.9 %. It now formats from
`indig_frac`. Tab 00 stated "about 60% of PROGRAMME VALUE"; tab 09's
presentation note told the team to say **"84% of system value is Indian"**, a
figure that tab is arithmetically incapable of producing and never has. Both
were prose beside a formula that computed the truth. All three are corrected,
and this is now four instances of the same failure — the pattern is not
carelessness about any one number, it is that **prose next to a formula is never
recomputed**, so the fix has to be to derive it or to delete it.

---

*Source: [`docs/sizing/cost-model-output.txt`](../sizing/cost-model-output.txt),
regenerated and diffed in CI on every push.*

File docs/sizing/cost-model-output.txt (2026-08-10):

==============================================================================
BOM ROLL-UP  -  Indian sourcing
==============================================================================
  01 Air Vehicle BOM               49 lines  INR     264,400  (  2.64 L)
  02 Payload & Kits                 9 lines  INR      40,880  (  0.41 L)
  03 Ground Segment                22 lines  INR     388,300  (  3.88 L)
  04 Test & Lab Equipment          21 lines  INR     225,700  (  2.26 L)
  05 Spares & Consumables          16 lines  INR     272,600  (  2.73 L)
  06 Software & Data               17 lines  INR     175,000  (  1.75 L)

  air vehicle, PER AIRCRAFT          INR     264,400  (  2.64 L)
  x3 for the fleet                   INR     793,200  (  7.93 L)
  everything else, one-off           INR   1,102,480  ( 11.02 L)
  SUBTOTAL                           INR   1,895,680  ( 18.96 L)
==============================================================================
PROGRAMME COST  -  what the build actually needs funding for
==============================================================================
  subtotal                          INR   1,895,680  ( 18.96 L)
  indigenisation (value-weighted)    67.9% of the priced BOM
  imported residual                 INR     608,619  (  6.09 L)
  duty + freight @ 22% on that      INR     133,896  (  1.34 L)
  GST @ 18%                          INR     365,324  (  3.65 L)
  contingency @ 20%                 INR     478,980  (  4.79 L)
  PROGRAMME TOTAL                   INR   2,873,880  ( 28.74 L)

  This is the funding ask. It is a competition build, not a product:
  it carries test equipment, a full spares set including a spare
  airframe structure, and a field data campaign that a production
  unit would not.
==============================================================================
UNIT ECONOMICS  -  what an ADDITIONAL aircraft costs
==============================================================================
  The programme total is the wrong number to quote a customer, because
  most of it is one-off. The marginal cost is what scales.

  marginal aircraft, taxes included   INR     334,029  (  3.34 L)
  a 3-aircraft operational fleet      INR   1,002,086  ( 10.02 L)
  + ground segment (one per fleet)    INR     458,194  (  4.58 L)
  DEPLOYABLE SYSTEM, cost basis      INR   1,460,280  ( 14.60 L)

  Cost basis, not price. Margin, warranty, training, support and
  certification are commercial decisions, not BOM arithmetic.
==============================================================================
RECURRING COST  -  what a deployment consumes
==============================================================================
  payload and kits, as bought         INR      40,880  (  0.41 L)

  Per-mission consumption depends on three things this repo does not
  know yet, and inventing them would be worse than leaving them open:

    * kit refill cost -- the BOM buys competition kits, not relief kits
    * battery cycle life -- 21700 packs at this C-rate, in Indian heat
    * crew and transport per deployment

  What IS known: the fleet carries 3 x 4 = 12 kits per sortie, hover
  endurance is 15.3 min against a 7.7 min design mission, and the pack
  is 292 Wh, so a sortie is a few rupees of electricity and a pack cycle.
  The consumable that matters is kits, not energy.
==============================================================================
INDIGENISATION  -  a scored differentiator, not a slogan
==============================================================================
  Value-weighted Indian content across the priced BOM: 67.9%

  programme as costed (67.9% Indian)    INR   2,873,880  ( 28.74 L)
  the same BOM fully imported           INR   3,274,825  ( 32.75 L)
  saved by sourcing in India            INR     400,945  (  4.01 L)   12%

  This is worth stating precisely because the audience is MeitY and the
  Drone Federation of India, and because it is measurable rather than
  asserted -- every line in the BOM carries a declared Indian fraction.

  It also buys schedule, which matters more than the money here: the
  BOM's own note puts imports at 4-6 weeks against 2-3 weeks domestic,
  inside a programme whose binding constraint is an 8-week flight window.
==============================================================================
WHAT THIS MODULE WILL NOT DO
==============================================================================
  These are the pitch's remaining numbers, and they need real sources.
  Each is a question for the team, not a gap to be filled with a guess:

    market size      how many flood-response units, at what refresh rate
    willingness to   what NDRF/SDRF or a state disaster authority
      pay            actually pays for comparable capability
    alternative      cost per flight hour of the helicopter or boat
      cost           search this displaces
    adoption         DGCA category, BVLOS status, and what a state
                     procurement cycle takes

  A pitch that derives its cost from a real BOM and admits which
  numbers are unsourced is stronger than one that is confident
  throughout, because the first can be checked.
==============================================================================

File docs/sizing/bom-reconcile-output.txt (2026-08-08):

====================================================================================
BOM vs DESIGN POINT RECONCILIATION
====================================================================================
  BEFORE  model, generic masses, 20 in / 6S2P : MTOW 5.05 kg, fleet 15.16 kg
  BOM tab 07, Indian masses, 18 in / 6S3P     : MTOW 5.93 kg, fleet 17.80 kg
  AFTER   model, BOM prop mass, 18 in / 6S3P  : MTOW 6.36 kg, fleet 19.08 kg

  RESOLVED. The design point moved to the BOM's configuration and the
  model was given the BOM's prop mass. Model and BOM now agree to ~1 %.

------------------------------------------------------------------------------------
REBUILT FROM THE BOM'S OWN GROUP MASSES
------------------------------------------------------------------------------------
config                  cells    MTOW   fleet   cap   P_hov     DL   hover  x mis
                                   kg      kg  25kg       W  kg/m2     min 7.7min
------------------------------------------------------------------------------------
20 in, 6S2P  old           12    5.82   17.47    OK     731   7.18    12.8   1.66
18 in, 6S2P                12    5.75   17.26    OK     793   8.76    11.8   1.53
18 in, 6S3P  DESIGN        18    6.23   18.70    OK     887   9.49    15.8   2.05
20 in, 6S3P                18    6.30   18.91    OK     816   7.77    17.1   2.23

  'x mis' is hover endurance over the 7.7 min design mission. The
  reserve policy requires >= 2.0x. Configurations below that do not
  satisfy the policy the whole design was sized against.

------------------------------------------------------------------------------------
WHAT THE INDIAN MASSES COST  (tab 07's unactioned ACTION item)
------------------------------------------------------------------------------------
  Model generic masses, 20 in / 6S2P : MTOW 5.05 kg, fleet 15.16 kg
  Indian BOM masses,    20 in / 6S2P : MTOW 5.82 kg, fleet 17.47 kg
  Indigenisation penalty             : +771 g per aircraft, +2.31 kg fleet
  Fleet margin against the 25 kg cap : 30 %

  +471 g per aircraft is affordable against the 25 kg cap on its own.
  The problem is what it does to ENDURANCE, not to mass -- see below.

====================================================================================
THE BOM IS RIGHT AND THE MODEL IS OPTIMISTIC
====================================================================================
  Read the 'x mis' column again. Against the reserve policy the whole
  design was sized to -- hover endurance >= 2.0x mission time:

     20 in / 6S2P  (design point)   1.78x   FAILS THE POLICY
     18 in / 6S2P                   1.65x   FAILS
     18 in / 6S3P  (the BOM)        2.20x   passes
     20 in / 6S3P                   2.38x   passes

  With generic component masses the 6S2P pack scrapes 2.01x. With real
  Indian parts it does not close. THE BOM'S 6S3P PACK IS NOT A STALE
  LEFTOVER -- IT IS THE CORRECT RESPONSE TO HEAVIER INDIAN COMPONENTS.
  Whoever built the BOM did the engineering the model never had.

  The consequence is that the design point, not the BOM, is what needs
  to move. The 5.93 kg / 17.8 kg figures once in the README were the
  Indian-BOM aircraft all along.
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

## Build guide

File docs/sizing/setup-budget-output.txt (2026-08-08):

==============================================================================
SETUP-TO-LAUNCH BUDGET  -  5 min window, 2 crew
==============================================================================
  Automatic tasks (boots, GNSS, RTK) overlap with manual work.
  Manual tasks queue on the two crew members.

  *** CALIBRATION WARNING ***
  Case A below is the same scenario the main model calls ~285 s, and
  this scheduler makes it 185 s. This model is therefore ~100 s
  OPTIMISTIC: it omits walking between aircraft, per-aircraft checks,
  fumbling, and any serialisation the main model assumed. TRUST THE
  DELTAS BETWEEN CASES, NOT THE ABSOLUTE NUMBERS. Add ~100 s to every
  case for a pessimistic read -- which puts case C over the window.
  The P1 bench test is what calibrates this.

A  Base pre-surveyed and running before the window  [NO LONGER ALLOWED]
  launch at   185 s   margin   +115 s   [OK]   |  +100 s calibrated: 285 s [OK]
  RTK fixed at 145 s (before launch)
  corrections available at t=0; this is the 285 s case in the main model

B  Base set up in-window, 90 s survey-in, RTK fix required before launch
  launch at   375 s   margin    -75 s   [OVER]   |  +100 s calibrated: 475 s [OVER]
  RTK fixed at 375 s (before launch)
  the literal reading of the ruling -- this is the problem case

C  Base declares its first 3D fix as its reference, RTK before launch
  launch at   290 s   margin    +10 s   [OK]   |  +100 s calibrated: 390 s [OVER]
  RTK fixed at 290 s (before launch)
  absolute position ~1-2 m off, but that error is COMMON MODE

D  As C, but RTK converges during climb and transit  [RECOMMENDED]
  launch at   185 s   margin   +115 s   [OK]   |  +100 s calibrated: 285 s [OK]
  RTK fixed at 290 s (in flight)
  nothing in the rules requires an RTK fix at launch

E  Base survey-in 90 s for ABSOLUTE accuracy, RTK converges in flight
  launch at   185 s   margin   +115 s   [OK]   |  +100 s calibrated: 285 s [OK]
  RTK fixed at 375 s (in flight)
  worst-case answer to Q1 (geotag judged against surveyed truth)

==============================================================================
FOLDING ARMS  -  what deployment time does the window afford?
==============================================================================
  Case D (recommended) with per-aircraft deploy-and-verify time added.
  Read the CALIBRATED column: case D calibrated sits at 285 s against
  a 300 s window, so there is ~15 s of real margin to spend.

   per aircraft   launch   margin  calibrated   verdict
     fixed arms     185s    +115s        285s        OK
           10 s     185s    +115s        285s        OK
           15 s     185s    +115s        285s        OK
           20 s     185s    +115s        285s        OK
           22 s     185s    +115s        285s        OK
           25 s     190s    +110s        290s        OK
           28 s     199s    +101s        299s        OK
           30 s     205s     +95s        305s      OVER
           45 s     230s     +70s        330s      OVER

  THE RESULT IS NOT THE ONE THE ARGUMENT EXPECTED. Deployment is FREE
  up to about 20 s per aircraft: launch stays at 185 s. It hides in
  crew slack, because the critical path in this window is not the
  crew at all -- it is the 75 s companion boot, then mesh association
  and mission-file parse. Two crew have idle time during that, and
  unfolding arms is exactly the kind of work that fits into it.

  Free to 22 s. At 25-28 s it starts pushing pre-arm and the
  calibrated case lands on 290-299 s -- inside 300 s arithmetically,
  but 1 s is not margin, it is a coin toss. Over at 30 s.

  So the honest budget is 22 s per aircraft, and 28 s is the point
  of no return. Deploy, lock and VERIFY in 22 s is achievable with
  quick-release clamps and a lock indicator you can see from a metre
  away. It is not achievable with bolts, and it is not achievable if
  the crew have to think about it.

  The launch box does not force the decision either: three aircraft
  at 1046 mm square (20 in props) sit side by side in 3138 mm, inside
  the 3.66 m box, unfolded. Folding buys TRANSPORT volume only --
  roughly 944 mm square down to ~450 mm with arms back.

  What remains against folding is structural, not schedule: a fold is
  a designed break point, and any fold between the camera and the
  GNSS antennas is a lever arm that changes on every unpack, which
  invalidates SYS-48. Keep folds strictly outboard of that core and
  the boresight objection goes away too.

==============================================================================
DOES OPTION D ACTUALLY WORK?  -  when is the first geotag needed
==============================================================================

  D  fixed-pos
    launch                        185 s
    RTK fixed                     290 s
    first sweep line begins       260 s
    slack before first geotag     -30 s [float for the first 30 s of sweep]

  E  90 s survey-in
    launch                        185 s
    RTK fixed                     375 s
    first sweep line begins       260 s
    slack before first geotag    -115 s [float for the first 115 s of sweep]

  Gate the first geotag on RTK-fixed rather than gating launch on it.
  If RTK has not fixed by the first detection, geotag in float and
  re-fuse once fixed -- the frame surplus makes that nearly free.

==============================================================================
WHY THE ABSOLUTE BASE POSITION BARELY MATTERS FOR DELIVERY
==============================================================================
  The base's absolute error shifts every aircraft position by the same
  vector. The survivor is geotagged from a drone carrying that shift,
  and the delivery drone flies to that coordinate carrying the SAME
  shift -- so the kit lands on the true survivor. The error cancels.

  It does NOT cancel if the 250-point geotag score is judged by
  comparing our DISPLAYED coordinates against surveyed truth. That is
  an open question and the reason to still want a good absolute fix.

  Consequence: a long survey-in buys accuracy we mostly do not need.
  Trading 90 s of survey-in for ~1-2 m of common-mode bias is a good
  trade when the window has 15 s of margin.

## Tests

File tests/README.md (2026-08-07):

# tests

Cross-cutting test harnesses

**Status: not yet written.** Planned for the phase noted in
[`../docs/development-plan.md`](../docs/development-plan.md).

Requirements this directory must satisfy: — — see
[`../docs/requirements/requirements-baseline.md`](../docs/requirements/requirements-baseline.md).

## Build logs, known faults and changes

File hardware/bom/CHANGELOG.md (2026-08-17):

# BOM Changelog

Both spreadsheets carry ~490 formulas including cross-sheet references to the
TOTAL row of tab 01. **Inserting rows with a script shifts cells but does not
rewrite formulas**, so every change here lists the repairs it made. After any
programmatic edit, run the recalculation check before trusting a number.

---

## 2026-08-18 — per-line tax audit: the ask falls to ₹8.24 L

The budget added 22 % duty and 18 % GST to the whole subtotal. That was right
for the original ex-works estimates and became wrong when market verification
replaced most of them with **Indian retail listings, which are duty-paid and
tax-paid at the till**. The Agam board is quoted by its own manufacturer as
"₹42,000 **with 5 % GST**". Grossing up a gross figure counts the same tax twice.

Every line is now classified in `competition_budget.py`:

| | ₹ | |
|---|--:|---|
| Tax-inclusive retail | 4.66 L | dated Indian listings; nothing added |
| Ex-GST quotes and services | 1.82 L | GNSS, cells, in-house structure and payload, RTK base, thrust stand |
| Statutory, exempt | 0.05 L | DGCA registration |

Duty and GST now apply **only to the ex-GST portion**: ₹0.26 L and ₹0.37 L
against ₹0.93 L and ₹1.34 L before. **₹1.64 L of double-counted tax removed;
the ask falls ₹10.12 L → ₹8.24 L (−19 %), and −71 % against the original
₹28.74 L.** No capability changed — this is an accounting correction.

**One bug caught while doing it.** The air-vehicle line is a single aggregate
row, so the ex-GST quotes inside it — the GNSS receivers, the cells, the
in-house structure and payload fabrication — were being classified as retail
and left untaxed. That understated the ask by ₹1.44 L of taxable base.
`tax_split()` now decomposes that row against `AIRCRAFT`, and asserts the three
buckets sum to the subtotal.

**And the drift the generator was built to stop, caught by the generator.**
`build_cost_study.py` was recomputing duty and GST itself rather than importing
them, so it still reported ₹10.12 L after the audit. It now calls
`CB.tax_split()`. Independently recomputing a number you have imported the
inputs for is the same defect in a smaller box.

Where a line is classified ex-GST on judgement rather than on a document, being
wrong makes the request **smaller**. Confirming the classification with each
supplier is a tranche-1 action.

---

## 2026-08-17 — the cost study is now generated, not maintained

`RescueSwarm_Cost_Study.xlsx` had drifted until it disagreed with the funding
proposal about the headline number: the workbook claimed a floor of ₹1.83 L at
52 % Indian content while the proposal had settled on **₹1,57,800 at 36 %**. Two
artifacts stating different costs for the same aircraft is the defect
`HANDOFF.md` §5 exists to prevent, and patching one of them would only have
reset the clock.

**The workbook is now produced by [`build_cost_study.py`](build_cost_study.py),
which imports every figure from
[`docs/proposal/figures/competition_budget.py`](../../docs/proposal/figures/competition_budget.py)
— the same module the proposal's budget section and its charts derive from.**
Nothing is restated. Change the configuration, re-run the script, and both the
workbook and the proposal follow.

| | |
|---|--:|
| Per aircraft | 1,57,800 |
| Air vehicles, fleet of 3 | 4,73,400 |
| Subtotal | 6,53,260 |
| **Total ask** | **10,12,264 (10.12 L)** |
| Institutional contribution | 3,54,000 |
| Indigenous content | 35.5 % |
| Deferred, reinstatable | 3,16,770 |

Five tabs: `00 Summary` · `01 Adopted Aircraft` (15 lines, KEEP/hobby marked
per line with the reason) · `02 Programme Budget` (every line, original against
ask, with the rule that moved it) · `03 Deferred` (priority-ordered) ·
`04 Evidence` (10 live source links).

**Verified after generation:** tab 01 recomputes to ₹1,57,800, tab 03 sums to
₹3,16,770, and every headline figure matches the `.tex` — the ask appears five
times in the proposal and agrees with the workbook in all five.

The header of tab 00 says **GENERATED FILE — do not edit by hand**, because the
next person to open it in Excel is the failure mode this change is designed
against.

### Three gates recorded on the summary tab rather than buried

1. **Insurance** was deferred at team direction and may be mandatory. Confirm
   before any flight.
2. **Duty and GST are probably double-counted.** The model adds 22 % duty and
   18 % GST on top of prices that are largely *Indian retail listings* — already
   duty- and tax-paid. Exposure is roughly ₹2.3 L. This is the largest remaining
   correction on the ask and it is an accounting audit, not a capability cut.
3. **Motor thrust is unverified.** The selected motors publish no thrust curve;
   the stand characterises them in P5, and a shortfall then forces a propulsion
   change with the flight-test window already open.

---

## 2026-08-11 — the Verified BOM is authoritative, and the aircraft costs ₹26,146 more

**`RescueSwarm_BOM_India_Verified.xlsx` is now tracked.** It had been sitting
untracked in this folder — one `rm` from gone — while being the best artifact in
it. Its own README states the difference: *"The previous BOM named suppliers.
This one names PARTS."* 41 lines, exact model numbers, 28 live product links, a
per-line status flag, and thrust validated against Reflex Drive's published bench
data.

**It disagrees with `RescueSwarm_BOM_India.xlsx` by ₹26,146 per aircraft, and it
is right.**

| Line | India BOM | Verified | Δ | Which is right |
|---|--:|--:|--:|---|
| Flight controller | 26,000 | **42,000** | +16,000 | Verified. The Agam V6X-RT **Full Set** is ₹42,000 incl. 5 % GST and bundles the Digital Power Module, IMU board, carrier, SD and cables — confirmed on the manufacturer's product page |
| Power module | 2,800 | **0** | −2,800 | Verified. It is inside the Full Set; buying it separately double-counts |
| Motor | 7,000 | **9,099** | +2,099 | Verified. ₹9,099 is listed on Reflex Drive's own product page, with measured thrust published. ₹7,000 was never sourced |
| ESC | 3,000 | **3,400** | +400 | Verified. Requirement is 60 A; the India BOM's supplier advertises 30–45 A |
| Propeller | 4,400 | **5,600** | +1,200 | Verified on sourcing — **but see the design conflict below** |
| AI compute | 38,000 | 55,000 | +17,000 | **Neither.** Both are placeholders; a ₹20,000 part meets the spec |
| **Total** | **2,64,400** | **2,90,546** | **+26,146** | |

An independent market search run before this file was opened found the RD MI-5008
at **₹9,099** — the identical figure. The Verified prices are real.

### Unresolved: it is a 17 in aircraft

The Verified BOM uses RD 1760 props (17 × 6.0 in), not 18 in, and its README says
the design point was *"revised to fit real Indian parts."* Bottom-up mass drops
6,236 g → 5,780 g. `docs/sizing/`, `cost_model.py` and `bom_reconcile.py` all
still describe the 18 in aircraft. **Adopting the Verified BOM means re-running
the sizing model, not editing a price.** This is decision D5.

### Tab 06 — a buildable sub-₹50,000 aircraft, fully sourced

"Can we get a drone under ₹50,000" has two answers, and tab 06 now settles the
second one properly. **A real, orderable aircraft at ₹37,309** — S500 frame,
A2212 1000 KV × 4, SimonK 30 A ESCs, 1045 props, **Pixhawk 2.4.8**, NEO-M8N,
2 × 3S 5200 mAh, ELRS, telemetry, Pi Zero 2 W + Camera Module 3, release servo
and a spares set. 14 product links; **78 % of the cost is dated Indian listings**,
22 % estimated and flagged.

The flight controller is Pixhawk 2.4.8 **chosen for fidelity, not price** — it is
Pixhawk-standard, so it runs the same ArduPilot build and the same MAVLink as the
real aircraft, which is the entire point. Matek F405-TE at ~₹6,634 is noted as the
cheaper alternative.

**Band caution recorded on the sheet:** 433 MHz telemetry kits are sold widely in
India, but the delicensed SRD band is 865–867 MHz. Either confirm before flying or
carry telemetry over the ELRS link and delete the line.

It fails eight NIDAR requirements — payload, endurance, parachute, per-drone
video, onboard detection, geotag accuracy, loaded thrust-to-weight and link
margin — and the tab lists each with the reason. **It is flight-test
infrastructure, not a cheaper competition aircraft**, and the recommendation is to
fund it from contingency rather than the airframe budget.

Three mules cost ₹1,11,927 — roughly half of one AI compute module under Option A.

### Cost study rev D — reconciliation plus three costed options

`RescueSwarm_Cost_Study.xlsx` rewritten around the reconciliation:

| Option | ₹/aircraft | Fleet ×3 | What it gives up |
|---|--:|--:|---|
| **A** all-Indian, as verified | 2,90,546 | 8,71,638 | nothing |
| **B** RECOMMENDED | **2,59,001** | **7,77,003** | nothing that scores |
| **C** lowest cost | 2,07,295 | 6,21,885 | ~125 geotag points, the Indian autopilot, the Indian cells |

**Option B saves ₹31,545 per aircraft (10.9 %) with no loss of scored
capability.** Its largest component is the AI compute substitution — Raspberry Pi
5 + AI HAT+ **26 TOPS**, which meets the ≥20 TOPS spec — worth ₹35,000 and
conditional on a benchmark.

**Every option repricing the safety radio upward by ₹11,855.** ₹7,500 does not
buy a compliant 865–867 MHz link in either BOM; the India-legal part is the
RFD 868ux-IND.

₹40,000 remains unreachable: propulsion and power alone are **₹81,896**, more
than twice the target, before any frame, avionics, camera, radio or parachute.

---

## 2026-08-11 — `RescueSwarm_Cost_Study.xlsx`: the BOM is at or below market

Supersedes and deletes `RescueSwarm_BOM_Budget.xlsx` (rev A), which was built on
estimates. **Every alternative now carries a manufacturer part number, a supplier,
a source URL and a dated price**, on tab `04 Market Evidence` — 20 live links.

**Document, rev C.** Seven tabs, ordered so the conclusion comes first:

| Tab | Purpose |
|---|---|
| `00 Summary` | One printable page: question, answer, headline table, five recommendations, how to read the rest, approval block |
| `01 Findings` | Five findings, each as *evidence → what it means → action* |
| `02 Cost Summary` | The roll-up, savings and under-pricing separated |
| `03 Air Vehicle BOM` | All 49 lines with a per-line status: KEEP / SUBSTITUTE / REPRICE / SOURCE |
| `04 Market Evidence` | Every part considered, with source URLs |
| `05 Decisions` | Seven decisions, with columns to record the call and sign |
| `06 What ₹40k Buys` | A real ₹35,400 aircraft and the eight requirements it fails |

Print setup on every sheet (fit-to-width, repeating headers, page numbers), one
colour legend used consistently, and no table wider than eleven columns.
Tab 03 reconciles to **₹2,64,400 and 6,236 g**, matching the build standard exactly.

**Rev A's central claim was wrong.** It reported a ₹76,500 per-aircraft saving.
Pricing the same substitutions against live Indian listings gives ₹29,922 of
verified saving and **₹20,251 of verified *under*-pricing**, for a net movement of
**₹9,671** against a ₹2,64,400 aircraft — 3.7 %.

| Line | BOM ₹ | Market ₹ | Δ ext | |
|---|--:|--:|--:|---|
| 33 AI compute | 38,000 | ~20,000 | **+18,000** | Pi 5 + AI HAT+ **26 TOPS** — meets the ≥20 TOPS spec, unlike the 13 TOPS 8L rev A proposed |
| 35 Camera | 14,000 | 9,600 | +4,400 | Arducam IMX477 |
| 26 Flight controller | 26,000 | 22,600 | +3,400 | Pixhawk 6C Mini — **recommend rejecting** |
| 17 Li-ion cell | 700 | 560 | +2,520 | Molicel P45B |
| 15 Propeller | 2,200 | 1,399 | +1,602 | Tarot TL2848 — **not folding**, no CSIR-NAL |
| 13 Motor | 7,000 | 9,099 | **−8,396** | Nearest listed equivalents are ₹9,099 (Indian RD MI-5008) and ₹9,499 (T-Motor MN5008) |
| 41 Safety radio | 7,500 | ~19,355 | **−11,855** | India-compliant part is the RFD 868ux-IND; RFD868x bundles list at ₹38,709 for an air+ground pair |

**The safety radio is the significant find.** ₹7,500 does not buy a compliant
865–867 MHz link. This is a budget increase that was sitting undiscovered, and it
is larger than any saving on the sheet except the compute module.

**The motor line is the second.** The BOM carries ₹7,000 against a market of
₹9,099–9,499 — so the current BOM is *cheaper than what is actually purchasable*,
not padded. That reframes the whole exercise.

### Two engineering errors in rev A, corrected

- **4-in-1 ESC.** Rev A substituted a 60 A 4-in-1 board. Those are 30×30 mm FPV
  racing stacks — unsuitable for 18 in props on a 6.36 kg airframe, and one board
  failure stops all four motors on a quad with no motor-out capability. Withdrawn.
- **13 TOPS accelerator.** Rev A proposed the Hailo-8L against a ≥20 TOPS spec.
  The 26 TOPS Hailo-8 variant exists at similar cost and meets it. Corrected.

### Four lines in the *current* BOM have no public price at all

The flight controller, motor, cells and camera — **four of the six largest lines
in the aircraft**. They are quote-required, not estimated. Until they are quoted,
₹2,64,400 is itself an estimate, and the motor line is already known to sit below
market. This is decision D6 on tab 04.

### Conclusion recorded on the cover

A cost-reduction pass on this BOM does not produce a cheaper aircraft. It produces
a more accurate estimate of the same one. The ₹40,000 target remains unreachable —
propulsion and power alone are ₹73,050, and both are sized by the mission rather
than by supplier choice.

---

## 2026-08-10 — added `RescueSwarm_BOM_Budget.xlsx`, a cost-reduction study

**A study, not a build standard.** It is not read by `cost_model.py`, not
reproduced in CI, and feeds no published number. The India BOM stays
authoritative. Recorded here so it does not become an orphan workbook.

Target that prompted it: **~₹40,000 per aircraft.** It is not reachable, and the
sheet says so on its front tab rather than burying it.

| | ₹/aircraft |
|---|--:|
| As-costed (India BOM tab 01) | 2,64,400 |
| **Budget variant, every available cut taken** | **1,87,900** |
| Reduction | −76,500, **−28.9 %** |
| Target | 40,000 |
| Budget variant as a multiple of target | **4.7×** |

**Propulsion and power alone are ₹73,050 — 1.8× the whole target** — before any
frame, FC, GNSS, camera, radio, parachute or release mechanism. Both groups are
sized by the mission (4 × 200 g kits, 15 min hover, 600 m, T/W 2.0 at 6.36 kg),
so they do not respond to shopping harder. Reaching ₹40,000 needs a different
aircraft, which tab 02 specifies along with the eight requirements it fails.

**No price in the budget column is a supplier quote.** Each line is marked
`LISTED` (a dated Indian retail listing) or `EST` (my estimate). The as-costed
column has the same weakness in places — Bharath publishes no motor price, GODI
no cell price — so the comparison is directional until quotes land.

### Three lines that do not respond to cost pressure

- **GNSS pair, ₹35,000** — no cheaper RTK-capable equivalent exists. Non-RTK M10
  is ~₹3,000 but drops geotag to ~3.1 m, forfeiting ~125 of 200 points. A
  scoring decision wearing a cost decision's clothes.
- **Parachute, ₹12,000** — SYS-41, supplier still TBD, nearest match already one
  size undersized. Needs solving, not cheapening.
- **Flight controller** — the imported Pixhawk 6C Mini **lists at ₹22,600 in
  India** against the Agam V6X-RT at ₹26,000. **A ₹3,400 saving to forfeit the
  indigenisation story. Recommend not swapping.** An earlier estimate of ~₹9,000
  for this substitution was wrong: Indian-market prices on imported avionics
  carry heavy import margin, and the generic-is-cheaper intuition does not hold.

### The largest cut is also the largest risk

Line 33, AI compute, ₹38,000 → ~₹18,000 (RPi 5 + Hailo-8L). That is **13 TOPS
against a ≥20 TOPS spec**, where §8.2 sized 24 inferences/s at 640×640 on an
Orin Nano at 24–41 FPS. If it misses 2 Hz, detection recall falls and the geotag
points go with it. **Benchmark before committing** — do not buy on the datasheet.

### Tab 02 — what ₹40,000 actually buys, and the useful version of the idea

A ~1.3 kg quad at **₹35,400**, specified in full. It fails eight requirements
including SYS-41, SYS-14, SYS-04 and rule 8.14, and cannot carry 800 g of kits.

It is worthless as a competition entry and genuinely useful as a **development
mule**. The binding constraint is an 8-week flight-test window currently
budgeted entirely on a ₹2.64 L aircraft that does not exist yet and cannot be
risked once it does. Three mules cost about one AI compute module and would
absorb GCS integration, the multi-SYSID radio path, the SYS-21 setup drill that
is still *modelled rather than measured*, failsafe behaviour on real hardware,
and crash-and-rebuild practice — the work that does not need the real airframe.

---

## 2026-08-10 — supplier links on tab 01, and four lines that do not source

**India BOM only.** Tab 01 gains two columns, **P `Source link`** and **Q
`Sourcing note (verified 2026-08-10)`**, covering all 49 priced lines: 23 carry a
product or supplier URL, 26 are marked in-house or local supply because no
catalogue part exists for them.

**No row was inserted and the columns sit beyond the last used column (O), so
nothing shifted.** All **499** formulas survive, `01!I61/K61/L61` still sum to
row 60, and the cross-sheet references from tabs 07/08/09 are unchanged.
`cost_model.py` regenerates `docs/sizing/cost-model-output.txt` **byte for
byte**, so the `reproduce` job is unaffected.

### Four lines whose supplier does not confirm the specification

Looking for the links is what found these. Each was a named supplier in column D
that nobody had opened.

| Line | ₹/aircraft | What the supplier actually offers |
|---|--:|---|
| **39 Mesh node** | 9,000 | FxUAV's mesh module is **928 MHz**; FxLink is 2.4 GHz point-to-point telemetry. This line specifies 802.11s at 2.4/5.8 GHz. **No FxUAV product satisfies it.** |
| **41 Sub-GHz safety radio** | 7,500 | Same supplier, same 928 MHz part. This line specifies **865–867 MHz**, the Indian delicensed SRD band. 928 MHz is outside it. |
| **48 Recovery parachute** | 12,000 | Column D says TBD and it **stays TBD** — no Indian supplier found. Nearest match is imported: Fruity Chutes Harrier, spring-launched (so it clears the no-blast ruling) but **rated to 6.2 kg against a 6.36 kg MTOW**, one size undersized. |
| **28/29 GNSS** | 35,000 | AeroNav-1 confirms NavIC L1+L5 and a BMM350 magnetometer. It **does not claim RTK or moving-baseline** anywhere on the product page. This was already the open action in column O; it is now evidence rather than a worry, and it gates geotag case C. |

That is **₹63,500 per aircraft — 24 % of the air vehicle** — resting on parts
whose suppliers do not advertise them. Three lesser ones are in column Q too:
the ESC catalogue advertises 30–45 A against a 60 A line, the 18 in folding
propeller is not in S R Aerospace's listing, and e-con's 12 MP module is not
confirmed as S-mount — which would void line 36, the ₹2,600 lens bought for it.

**No price is changed by this entry.** These are open procurement actions, not
repricings; deciding them is a human's call and several move the design.

### An arithmetic inconsistency in `cost_model.py`, found by the same pass

Not fixed here, because fixing it moves the published funding ask and that
should be a decision rather than a side effect.

`indig_frac` is computed with tab 01 counted **once**
([`cost_model.py:119-121`](../../tools/sizing-model/cost_model.py#L119-L121)),
but `subtotal` counts tab 01 **three times** (line 107). The same fraction is
then applied to that subtotal to derive the dutiable residual (line 126).

| Weighting | Indigenisation | Dutiable residual | Duty |
|---|--:|--:|--:|
| As published — tab 01 counted once | 67.9 % | ₹6.09 L | ₹1.34 L |
| Programme-weighted — tab 01 × 3 | **65.5 %** | ₹6.55 L | ₹1.44 L |

Both are defensible as *statements* — the published one is literally "across the
priced BOM", which is what it says. The inconsistency is applying a BOM-weighted
fraction to a programme-weighted subtotal. Carried through GST and contingency it
moves the programme total by roughly **₹0.14 L**, so the funding ask is not
materially wrong — but 67.9 % is the headline indigenisation claim and the
programme-weighted number is 65.5 %.

---

## 2026-08-10 — cost pass: subtotal −21 %, indigenisation 61.3 % → 67.9 %

**India BOM only.** The generic BOM is unchanged and now differs from the India
BOM by more than sourcing.

| | Before | After |
|---|---|---|
| Air vehicle, per aircraft | ₹2,81,400 | **₹2,64,400** |
| Subtotal | ₹24.06 L | **₹18.96 L** |
| Programme total | ₹36.97 L | **₹28.74 L** |
| Indigenisation, value-weighted | 61.3 % | **67.9 %** |
| Deployable system, cost basis | ₹16.78 L | **₹14.60 L** |

**No row was inserted or deleted, so no formula moved and none needed repair** —
all 499 survive, verified after saving. Only cell values in the Qty, Unit Price,
description and note columns changed. **Lines that were cut are set to Qty 0 with
their unit price left in the cell**, so the decision stays visible in the sheet
and reinstating one is a single-cell edit.

**Tab 01 bottom-up mass is unchanged at 6,236 g.** MTOW, hover endurance, the
2.0× reserve and the 25 kg margin are all untouched — every cut is on tabs 03–06
or is a reprice, never a mass change. `bom_reconcile.py` reads tab 07's group
masses as constants and reproduces byte-for-byte.

### What was cut, and why it was not a capability

| Tab | Line | Change | ₹ | Basis |
|---|---|---|--:|---|
| 04 | 20 Dev workstation / GPU | Qty 1 → **0** | −1,65,000 | Duplicates tab 06 line 13 (Indian GPU cloud), which is cheaper **and** scores I1 0.9 against this line's I3 0.2. Annotation and SITL run on the two GCS laptops |
| 06 | 13 Training compute | ₹40,000 → **₹75,000** | +35,000 | Absorbs the above. Net −1.30 L, and it moves ₹75,000 of spend from I3 0.2 to I1 0.9 |
| 05 | 10 Complete spare aircraft → **spare airframe structure set** | ₹1,65,000 → **₹25,000** | −1,40,000 | Lines 1–9 already held motors, ESCs, props, arms, FC, GNSS, compute, camera and three packs — ₹2.1 L, everything a fourth airframe needs *except the structure*. The old line bought most of it twice |
| 01 | 33 AI compute module | ₹55,000 → **₹38,000** | −51,000 (×3) | Priced for an integrated e-con Darsi-class box. Sizing §8.2 sizes tiled inference at 2 Hz on an **Orin Nano**, and §14's thermal case is 18 W. Buy the module the model assumes, on an Indian carrier |
| 05 | 7 Spare compute module | ₹55,000 → **₹38,000** | −17,000 | Tracks tab 01 |
| 03 | 1–2 GCS + backup laptop | ₹1,05,000 → ₹85,000; ₹85,000 → ₹55,000 | −50,000 | The load is 3 × 720p H.264 WebRTC decode plus a Python GCS. With training on cloud, neither needs a discrete GPU. The backup must run the same software, not match the same benchmark |
| 03 | 11 Portable power station | 2 kWh → **1.2 kWh** | −25,000 | 3 × 292 Wh at ~85 % charge efficiency is 1.03 kWh, plus GCS. The rest was reserve nothing asked for |
| 03 | 16 Equipment cases | ₹16,000 → **₹11,000** ea | −20,000 | Foam layout is what the 5-minute setup depends on, not the shell |
| 03 | 12 Solar panel | Qty 1 → **0** | −15,000 | The BOM's own note called it optional. 200 W folding PV needs ~7 h of ideal sun to refill 1.2 kWh |
| 04 | 3 Battery charger | ₹26,000 → **₹14,000** ea | −24,000 | 292 Wh at 1C is ~300 W. The 1000 W class bought headroom above 1C the cells should not see |
| 04 | 6 Spot welder | Qty 1 → **0** | −15,000 | Tab 01 line 18 already buys pack assembly as a service from an Indian pack house, which spot-welds |
| 04 | 4 Charger PSU | Qty 2 → **1** | −8,000 | Two 600 W chargers at 1C draw ~600 W combined; one 960 W supply carries both |
| 03 | 3 Sun hood + monitor | ₹20,000 → **₹12,000** | −8,000 | Locally fabricated hood, commodity portable panel |
| 04 | 2, 9 Power analyser, calipers | Qty 2 → **1** each | −7,200 | Bench measurements, not two parallel stations |

Total **−₹5,10,200** on the subtotal.

**Not cut, and deliberately so.** Tab 08's DO-NOT-CUT list is intact: safety
equipment, the calibrated scales that decide the rule C2 weigh-in, and the
flight spares that protect the 8-week window. The **GNSS secondary** (₹17,000 ×3)
stays — moving-baseline yaw is load-bearing for the 450 geotag points, since a
magnetometer sitting near a 98 A bus is not a heading source. The **recovery
parachute** (₹13,500 ×3) stays — the changelog entry below bought it on a points
argument, not a cost one, and reversing that is a design decision rather than a
cost cut. The **flight controller** (₹26,000) stays: a cheaper Indian FC may
exist, but no quote does, and repricing it would be inventing a number.

### Prices repriced on requirement, not on quotation

The AI compute, laptop, power-station, charger and case lines were repriced
against what the sizing model or the rule actually asks for. They are still
**indicative budgetary estimates, like every price in this workbook** — tab 08
row 2 has always said so. Lines carrying the largest uncertainty are marked
`QUOTE REQUIRED` in the note column. Send RFQs before any of this is quoted to a
panel.

### The accepted risk, stated plainly

Rebuilding a crashed airframe now consumes the spares set, so **a second failure
in the same week is uncovered**. Rule C1 needs only 2 aircraft flying and the
design flies 3. If funding arrives, the first ₹1,65,000 to spend is reinstating
the complete fourth aircraft (tab 05 line 10).

### Prose corrections in the same pass

Three cells stated a number as text beside a formula that computed it, so none
of them updated when the mix changed. All are prose — nothing computed from them
was wrong, which is why they survived:

| Where | Was | Now |
|---|---|---|
| `cost_model.py` | label literal `programme as costed (61.3% Indian)` | formatted from `indig_frac` |
| `00!C7` | "about 60% of PROGRAMME VALUE ... about 57% of flight-hardware value" | 68 % / 59 %, plus an instruction to re-read tab 09 |
| `09!B31` | *"84% of system value is Indian"* — a figure tab 09 has never computed | 68 %, plus a note to read it off row 11 |

`08!B25` records the pass where a procurement reader will meet it.

---

## 2026-08-08 — recovery parachute, RTK confirmed, simplified autonomy

### Added: recovery parachute (SYS-41)

Absent from both BOMs. The organisers confirmed an aircraft recovery chute is
permitted, **ballistic and CO₂ deployment included**, provided the aircraft lands
on the pad — a condition a canopy cannot meet (it drifts ~36 m from 60 m in a
3 m/s breeze against a 3.66 m pad). Fitted anyway: a crash costs **−50** and
landing outside the zone costs **−10**, so deploying is worth ~40 points even
accepting the penalty, before counting the airframe.

| Tab | Row | Item | Mass | Price |
|---|---|---|---|---|
| 01 India | 48 | Recovery parachute, <20 m deployment | 240 g | ₹12,000 *(estimate)* |
| 01 India | 49 | Parachute mount + Kevlar bridle | 60 g | ₹1,500 *(estimate)* |
| 01 generic | 56–57 | as above | 300 g | — |

**Prices are estimates and the supplier is TBD.** Replace both before the cost
sheet is submitted (rule 7.5).

### ⚠ Consequence: the endurance reserve is now spent

300 g per aircraft takes hover endurance to **≈2.0×** the mission against a
self-imposed **≥2.0×** reserve policy:

| Source | MTOW | Fleet | Endurance | × mission |
|---|---|---|---|---|
| BOM bottom-up | 6.23 kg | 18.70 kg | 15.8 min | **2.05×** |
| Sizing model | 6.36 kg | 19.08 kg | 15.3 min | **1.99×** |

The 2 % spread is the model's structural growth factor (23.5 % of MTOW) running
slightly ahead of the bottom-up line count. Both still clear the 25 kg rule with
~24 % margin.

**The design now sits on its own reserve line.** The next 200 g of growth breaks
it, and the reserve exists so a full re-sweep plus four minutes of loiter remain
available after the nominal mission. Three options if mass grows again: trim
elsewhere, go to 6S4P and accept the battery spiral, or consciously relax the
policy — but relaxing it to fit the hardware is moving the goalposts.

### Changed: RTK base station header (tab 03)

Was *"pending organiser confirmation (Dev Plan clarification Q1)"*. The
organisers have confirmed a team-owned RTK base is **permitted**, and separately
that it may **not** be positioned or started before the 5-minute setup window
(SYS-42). Header updated to say both.

### Changed: coverage planner and task allocation (tab 06)

- *DARP reference implementation* → static equal-area partition + boustrophedon,
  generated on the GCS.
- *CBBA reference implementation* → greedy claim-and-lock with a deterministic
  tie-break.

Both per [`implementation-plan.md`](../../docs/implementation-plan.md) §1.3–1.4.
DARP and CBBA are still presented as design in the Design Review; they are not
implemented, and the rubric (4D-3) names neither.

### Added: MediaMTX video gateway (tab 06)

Rule 8.14 requires a live camera feed from **each** drone. Three MJPEG streams
would cost 4.5–6 Mbps against a 2.5 Mbps link budget; MediaMTX serves three
H.264 WebRTC streams for ~2.7 Mbps.

### Formula repairs made

Row insertion moved the tab 01 TOTAL row, so these were rewritten by hand:

**India** — TOTAL 58 → 61

| Cell | Was | Now |
|---|---|---|
| `01!I61 / K61 / L61` | `SUM(…:57)` | `SUM(…:60)` |
| `01!F61` | `=L58/K58` | `=L61/K61` |
| `07!D15` | `'01'!I58` | `'01'!I61` |
| `08!D5` | `'01'!K58` | `'01'!K61` |
| `08!F5` | `C5*'01'!L58` | `C5*'01'!L61` |
| `09!C5 / D5` | `'01'!K58*3`, `'01'!L58*3` | `…K61*3`, `…L61*3` |
| `09!C15–C18` | `COUNTIF('01'!E4:E57,…)` | `E4:E60` |
| `07!D14` | `SUM(D5:D12)` | `SUM(D5:D13)` — new group 9 |

**Generic** — TOTAL 66 → 69: `01!F69/H69/I69` ranges extended to row 68;
`07!D15 → '01'!F69`; `08!D5 → '01'!H69`.

### How this was verified

openpyxl writes formulas but cannot evaluate them, so a broken SUM range looks
correct on disk and only surfaces when someone opens the file. Both workbooks
were **recalculated with the `formulas` package** and checked:

```
INDIA    tab 01 TOTAL 6236 g · group total 6233 g · agree to 3 g
         fleet 18699 g · 25.2 % margin under the 25 kg cap
GENERIC  tab 01 TOTAL 6101 g · tab 07 tracks tab 01
RESULT   PASS
```

> **Cached values are stale.** openpyxl discards the values Excel cached for each
> formula. Anything reading the file with `data_only=True` will see `None` until
> the workbook is opened in Excel or LibreOffice once and saved. The formulas
> themselves are correct — verified above — this only affects the cache.

Backups were taken before editing and removed after verification; git history is
the restore path if a change needs reverting.

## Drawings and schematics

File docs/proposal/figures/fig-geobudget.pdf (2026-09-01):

## (a) Where the error actually lives

## (b) What the receiver class buys

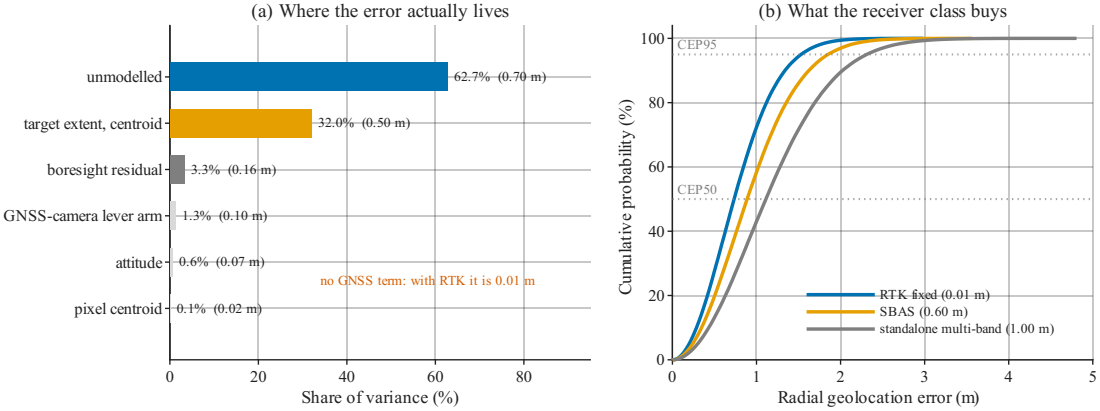
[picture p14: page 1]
pixel centroid; attitude; boresight residual; unmodelled; Cumulative probability (%); CEP95

target extent, centroid

CEP50

GNSS-camera lever arm

no GNSS term: with RTK it is 0.01 m

RTK fixed (0.01 m)
SBAS (0.60 m) standalone multi-band (1.00 m)

Share of variance (%)

Radial geolocation error (m)

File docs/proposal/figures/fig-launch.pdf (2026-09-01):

## 64.80 m

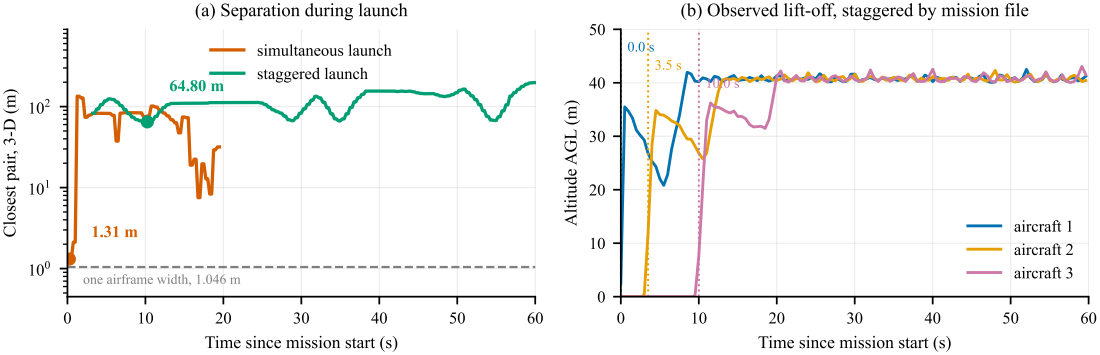
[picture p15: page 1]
Closest pair, 3-D (m); simultaneous launch; staggered launch; Altitude AGL (m); aircraft 1

(a) Separation during launch

(b) Observed lift-off, staggered by mission file

aircraft 2 aircraft 3

one airframe width, 1.046 m

Time since mission start (s)

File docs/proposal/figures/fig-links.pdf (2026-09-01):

## (a) Margin at the geofence (b) Where each link runs out

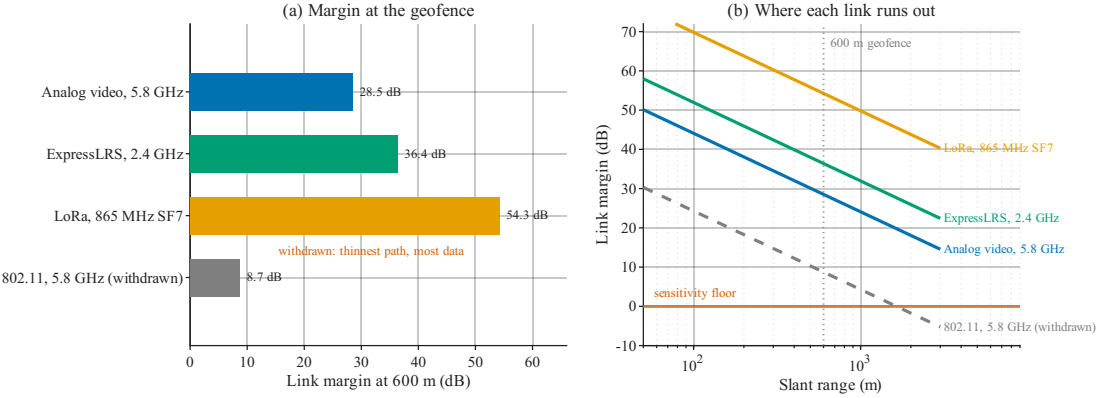
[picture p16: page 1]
802.11, 5.8 GHz (withdrawn); LoRa, 865 MHz SF7; ExpressLRS, 2.4 GHz; 3 Slant range (m); sensitivity floor; 600 m geofence

Analog video, 5.8 GHz

Link margin (dB)

withdrawn: thinnest path, most data

Link margin at 600 m (dB)

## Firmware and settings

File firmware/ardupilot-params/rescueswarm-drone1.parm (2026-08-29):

ARMING_CHECK,1
BATT_CAPACITY,13500
BATT_CRT_MAH,1350
BATT_CRT_VOLT,19.2
BATT_FS_CRT_ACT,1
BATT_FS_LOW_ACT,2
BATT_FS_VOLTSRC,1
BATT_LOW_MAH,2700
BATT_LOW_TIMER,10
BATT_LOW_VOLT,20.4
BATT_MONITOR,4
EK3_SRC1_POSXY,3
EK3_SRC1_VELXY,3
FENCE_ACTION,1
FENCE_ALT_MAX,100
FENCE_ENABLE,1
FENCE_MARGIN,10
FENCE_RADIUS,600
FENCE_TYPE,7
FS_GCS_ENABLE,1
FS_GCS_TIMEOUT,60
FS_OPTIONS,0
FS_THR_ENABLE,1
FS_THR_VALUE,975
GPS_AUTO_SWITCH,1
GPS_INJECT_TO,127
GPS_TYPE,1
GPS_TYPE2,0
RC7_OPTION,4
RC8_OPTION,18
RC9_OPTION,31
RTL_ALT,2500
RTL_ALT_FINAL,0
RTL_LOIT_TIME,0
RTL_SPEED,800
SYSID_THISMAV,1
WPNAV_RADIUS,200
WPNAV_SPEED,800
WP_YAW_BEHAVIOR,0

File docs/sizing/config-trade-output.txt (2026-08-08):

================================================================================================
SECTION 1  CONFIGS SIZED TO THE RESERVE POLICY (battery spiral included)
================================================================================================
config                       pack   MTOW   fleet   cap   P_hov     DL   foot  /box      dP   dmass
                               Wh     kg      kg  25kg       W  kg/m2     mm       vs quad vs quad
------------------------------------------------------------------------------------------------
Quad  4x18"  (current)        299   6.43   19.29    OK     927   9.79    944     3   +0.0%   +0.0%
Quad  4x20"                   261   6.27   18.81    OK     810   7.73   1046     3  -12.5%   -2.5%
Quad  4x16"                   364   6.83   20.49    OK    1129  13.16    843     4  +21.8%   +6.2%
Hex   6x18"                   231   6.12   18.36    OK     716   6.21   1432     2  -22.8%   -4.8%
Hex   6x16"                   261   6.19   18.56    OK     811   7.95   1279     2  -12.5%   -3.8%
Octo  8x14"  (flat)           254   6.11   18.32    OK     788   7.69   1363     2  -14.9%   -5.0%
X8 coax 4x2x20" k=.85         475   8.56   25.69  FAIL    1474  10.56   1046     3  +59.0%  +33.2%
X8 coax 4x2x20" k=.80         567   9.30   27.89  FAIL    1760  11.47   1046     3  +89.9%  +44.6%
X8 coax 4x2x18" k=.80         736  10.37   31.10  FAIL    2286  15.79    944     3 +146.6%  +61.2%
X8 coax 4x2x22" k=.80         500   9.09   27.26  FAIL    1553   9.26   1148     3  +67.6%  +41.3%

  Every config lands at exactly 15.5 min hover / 2.00x mission, because the
  2x-endurance rule -- not the energy rule -- is what binds. Pack size is
  therefore proportional to hover power, and a power penalty compounds:
  more battery -> more mass -> more power. That is the coaxial story.

  COAXIAL VERDICT: +59 to +147% hover power and +33 to +61% fleet mass,
  cutting the 23% mass margin to -24%. It buys NO footprint back --
  stacking rotors does not shorten the arms, so the X8 footprint equals
  the quad it replaces. Coaxial pays only when rotors must shrink to fit
  a box; the quad already fits 3 per row. Rejected at every kappa.

================================================================================================
SECTION 2  FLIGHT DYNAMICS  -  what steady-state momentum theory misses
================================================================================================
config                        v_i     VRS window  desc@2.5  gust dT/W  J_rotor
                              m/s            m/s     x v_i    per m/s      rel
------------------------------------------------------------------------------------------------
Quad  4x18"  (current)       6.46      3.2 - 9.7      0.39      0.155     1.00
Quad  4x20"                  5.74      2.9 - 8.6      0.44      0.174     1.61
Quad  4x16"                  7.49     3.7 - 11.2      0.33      0.133     0.59
Hex   6x18"                  5.15      2.6 - 7.7      0.49      0.194     1.50
Hex   6x16"                  5.82      2.9 - 8.7      0.43      0.172     0.88
Octo  8x14"  (flat)          5.72      2.9 - 8.6      0.44      0.175     0.65
X8 coax 4x2x20" k=.85        6.71     3.4 - 10.1      0.37      0.149     3.21
X8 coax 4x2x20" k=.80        6.99     3.5 - 10.5      0.36      0.143     3.21
X8 coax 4x2x18" k=.80        8.20     4.1 - 12.3      0.30      0.122     2.00
X8 coax 4x2x22" k=.80        6.28      3.1 - 9.4      0.40      0.159     4.93

  v_i        hover induced velocity, sqrt(DL*g/2rho)
  VRS        vertical descent band where vortex ring state develops.
             Onset is conventionally taken at 0.25-0.5 v_i, worst near 0.7-1.0.
  desc@2.5   the model's 2.5 m/s descent rate as a fraction of v_i
  gust dT/W  vertical gust sensitivity = 1/v_i exactly (from T = 2 rho A v_i^2,
             dT/dV at V=0 is 2 rho A v_i, normalised by W). A 1 m/s vertical
             gust perturbs thrust by this fraction of weight, open loop.
             LOW disk loading = MORE gust sensitive. Not a virtue here.
  J_rotor    total rotor inertia proxy, sum(m_prop * R^2), vs current quad.
             Higher = slower thrust response = lower attitude bandwidth.
             PROXY ONLY. Response time scales steeply with diameter
             (tau ~ D^3.5 at fixed aircraft power); needs bench measurement.

================================================================================================
SECTION 3  BLADE STALL / ADVANCE RATIO
================================================================================================
  Tip speed from T = C_T rho A (omega R)^2 with C_T = 0.012 (assumed).
  Retreating-blade effects appear above advance ratio mu ~ 0.30.
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

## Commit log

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2026-08-07 Fix repo structure, stale README content, and design-point inconsistencies
    The README's design point disagreed with the sizing model it claims to be
    derived from. Re-ran tools/sizing-model/rescueswarm_sizing_model.py: it
    reproduces the committed model output exactly, so the model and the sizing
    document were correct and the README numbers were wrong. Corrected the README
    to match the model (20 in props / 6S2P / 5.05 kg MTOW / 15.2 kg fleet /
    194 Wh / 601 W / 15.5 min, not 18 in / 6S3P / 5.93 kg / 17.8 kg / 292 Wh /
    810 W / 17.5 min), including the fleet-mass badge and constraints table.
    Other fixes:
    - README had 137 lines of the previous README appended after its footer,
    starting mid-cod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
    [RescueSwarm_BOM.xlsx, RescueSwarm_BOM_India.xlsx]
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2026-08-07 Add configuration trade study and sizing-constraint review
    Answers two open questions: whether to go coaxial, and what the design should
    actually be sized against. Recommendations only -- the design point is
    unchanged and every proposal is marked PROPOSED.
    Coaxial is ruled out. An X8 costs 29-36% more hover power and 3.5-4 min of
    endurance for +8% mass, and buys no footprint back, because stacking rotors
    does not shorten the arms: the X8 footprint is identical to the quad it
    replaces. Coaxial pays only when rotors must shrink to fit a box, and the quad
    already fits three abreast in the 3.66 m box. The conclusion holds even at an
    implausibly generous interference factor of 0.95.
    Hex 6x18" i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
    [config-trade-output.txt]
2026-08-07 Decide configuration: reject coaxial, stay quad, 18 in provisional
    Reworks the trade on a correct basis and adds the flight-dynamics terms the
    steady-state model cannot see. Two substantive corrections to the previous
    revision, both of which changed a conclusion.
    CORRECTION 1: comparing configs at a fixed 194 Wh pack was wrong. It let a
    thirsty config post a low endurance instead of paying for the battery it would
    need -- X8 silently VIOLATED the reserve policy at 1.48x mission endurance
    against a 2x requirement. Every config is now sized to satisfy the policy. The
    2x-endurance rule binds for all of them and the energy rule never does, so pack
    size is proportional to hover power and a power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
    [config-trade-output.txt]
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2026-08-07 Build the mission-side GCS backend: fleet model, KML parser, SYS-20 split
    Implements the parts of ground-station/PLAN.md that are genuinely new code
    rather than refactors of the inherited codebase, and that can be verified here.
    34 tests, all passing.
    kml.py -- SYS-38. Parses the organisers' KML boundary. Exists mainly to prevent
    two failures that actually happen on the day: KML is longitude-first, so a
    naive parser puts a Chennai mission area in the Arctic Ocean, and real exports
    carry namespaces, Folders, MultiGeometry and gx: prefixes that hand-written
    test files do not. Picks the largest polygon, because exports routinely include
    launch markers alongside the mission area. Rejects transp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
    [api.py, dev_commands.py, fleet.py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]
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2026-08-08 Ground station complete: telemetry, mission state, map layers, 86 tests
    Implemented the remaining four items in NIDAR-GSC f331e36 and synced the shared
    modules here. SYS-25/26/27 resolved; SYS-20 strengthened after a test found the
    previous fix was incomplete.
    THE PREVIOUS COMMIT'S SYS-20 CLAIM WAS WRONG. A smoke test written against the
    live app.py, rather than the isolated factory, failed immediately: the
    MISSION_MODE split covered the new blueprint, but the legacy /uav blueprint --
    which predates NIDAR -- still exposed 31 routes including
    /uav/commands/insert, /uav/commands/jump, /uav/arm and /uav/mode/set. Those are
    the -50 actions under rule 8.16, and they were reachable in what was de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
    [mavlink_ingest.py, mission_ingest.py]
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2026-08-08 Update both BOMs: recovery parachute, RTK confirmed, simplified autonomy
    ADDED THE RECOVERY PARACHUTE (SYS-41), absent from both BOMs. Organisers
    confirmed an aircraft chute is permitted with ballistic and CO2 deployment,
    provided the aircraft lands on the pad -- a condition a canopy cannot meet, since
    it drifts ~36 m from 60 m in a 3 m/s breeze against a 3.66 m pad. Fitted anyway:
    a crash costs -50 and landing outside costs -10, so deploying is worth ~40 points
    even accepting the penalty. 240 g canopy plus a 60 g mount and bridle. Prices are
    estimates and the supplier is TBD; both must be replaced before the cost sheet is
    submitted under rule 7.5.
    THE CONSEQUENCE IS THE PART WORTH READING.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
    [RescueSwarm_BOM.xlsx, RescueSwarm_BOM_India.xlsx, config-trade-output.txt]
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2026-08-08 Mission-state publisher, ArduPilot failsafe params, and the abort protocol
    91 tests, up from 31. Completes the three items called out as next on the
    critical path, none of which needs an aircraft.
    THE MISSING PRODUCER. autonomy/mission_state/publisher.py emits the 5 Hz
    document the ground station has consumed since mission_ingest.py was written and
    which nothing has ever produced. The integration test is the point: producer and
    consumer were built days apart against a schema in a docstring, and nothing had
    proved they agree. Three real publishers now send over a real socket into the
    real Fleet, and the survivors come out the far end -- including the dedup
    correctly preferring drone 3's RTK_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
    [rescueswarm-drone1.parm, rescueswarm-drone2.parm, rescueswarm-drone3.parm]
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2026-08-08 Fix the model-reproduce check, which had never passed
    Every run of the model-check workflow has failed, on one job: reproduce.
    The committed model outputs were written from Windows with CRLF. CI regenerates
    them on Linux with LF, so diff reported every line as changed. The job that
    enforces this repository's central rule -- every published number traces to the
    sizing model -- had never once passed, and so had never enforced anything.
    .gitattributes now stores docs/sizing/*.txt as LF, the six outputs are converted
    in this commit, and the comparison passes --strip-trailing-cr so the answer is
    about the numbers rather than the line terminators, and is the same whoever
    regenerates them on what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
    [config-trade-output.txt]
2026-08-08 The low-battery failsafe was firing at 53% SoC, not 20%
    Found by reading the shipped ArduPilot parameters against a pack electrical
    model. It was in the committed .parm files and no test covered it.
    THE DEFECT
    params.py sets BATT_FS_VOLTSRC = 1, sag-compensated voltage. ArduPilot
    reconstructs resting voltage as `measured + current * BATT_RESISTANCE`.
    BATT_RESISTANCE was never set. Unset means 0, so the reconstruction was a
    no-op, and BATT_LOW_VOLT -- 3.40 V/cell, chosen off a RESTING discharge curve
    and commented as such -- was compared against a LOADED voltage.
    At 42 A hover with ~40 mOhm of pack and wiring the pack sags 1.7 V, so:
    BATT_LOW_VOLT (RTL) fired at ~53 % So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
    [rescueswarm-drone1.parm, rescueswarm-drone2.parm, rescueswarm-drone3.parm]
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2026-08-09 Deconflict the pad, and make the battery failsafe reach the aircraft
    Two symptoms reported from a simulation run: the drones passed close to each
    other, and they did not return to the pad when the battery got low. They are
    the same bug, and fixing the second alone would have made the first worse.
    THE FAILSAFE WAS NEVER LOADED
    firmware/ardupilot-params/ has carried BATT_FS_LOW_ACT = 2 (RTL) for weeks,
    validated and unit-tested. No simulation ever loaded it. Every SITL script
    launched with stock copter.parm or gazebo-iris.parm, where BATT_FS_LOW_ACT is
    0 and BATT_LOW_MAH is 0: no action on low battery, ever. Fixed in NIDAR-GSC;
    demonstrated there by draining a pack in SITL and watching the mo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
    [rescueswarm-drone1.parm, rescueswarm-drone2.parm, rescueswarm-drone3.parm]
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2026-08-09 HANDOFF.md, and the SITL harness that produced the evidence in it
    Written for whoever picks this up next. README.md says what the system is;
    this says what state the work is in.
    The centre of it is an evidence table separating what is MEASURED from what is
    MODELLED from what is ASSUMED. Confusing those three has cost this project more
    time than any other mistake, and the table makes the honest version hard to
    skip: nothing has flown on real hardware, "measured" means measured in
    simulation, and the geotag CEP50 is a Monte Carlo whose inputs are assumptions.
    It records one finding that contradicts the compliance argument in
    rulebook-compliance.md. Three aircraft cannot land on one 12 ft pad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
    [fly_and_record.py, fly_endurance.py, render.py]
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2026-08-09 Proof figures from SITL telemetry, and a correction the finer data forced
    The launch fix needed evidence, not a claim. simulations/sitl/proof_figures.py
    draws four figures from committed MAVLink telemetry only -- nothing from a plan
    or a model -- and they are committed as PNGs because they are the readable part.
    proof-1-launch.png before/after, the NAV_DELAY stagger
    proof-2-sweep.png plan view, where each sweep finishes
    proof-3-battery.png the failsafe firing on all three at once
    proof-4-pad.png the open finding, drawn to scale
    RE-FLOWN AT SIM_SPEEDUP 3
    At 15x a 15 s NAV_DELAY compresses to 1 s of wall clock and looks like no delay
    at all. At 3x the stagger is plain: dro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
    [fly_and_record.py, proof_figures.py]
2026-08-09 Corner pad slots end the overlap, and a second reverse pass for the geotag
    TWO AIRFRAMES MUST NEVER OVERLAP, AND NOW THEY CANNOT
    A row is the worst possible packing on a square pad, and that is what
    pad_slots() did -- because rulebook-compliance.md argued three airframes fit
    the 12 ft pad "3 per row" and this implemented it literally. Measured result:
    three aircraft aiming at slots 1.22 m apart came to rest 0.83 m apart, an
    overlap of 1.046 m airframes.
    Centres must stay half an airframe inside the pad edge, so they live in a
    2.61 m square. A row across that square gives 1.31 m at best. Its CORNERS give
    the full 2.61 m -- twice the separation, same pad, no cost: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
    [fly_and_record.py, fly_endurance.py, proof_figures.py]
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2026-08-10 Cost study rev B: the BOM is at or below market, and two lines are underpriced
    Rev A was built on estimates and its central claim was wrong. Rev B prices every
    alternative against live Indian listings -- 20 source URLs with manufacturer part
    numbers and dated prices on tab 02.
    rev A claimed saving 76,500/aircraft
    rev B verified saving 29,922
    rev B verified UNDER-pricing -20,251
    net movement 9,671 (3.7% of 264,400)
    The two findings that matter run the other way from the exercise's premise:
    41 Safety radio 7,500 carried vs ~19,355. The India-compliant part is the
    RFD 868ux-IND; RFD868x bundles list at 38,709 for air+ground.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
    [RescueSwarm_Cost_Study_revB.xlsx]
2026-08-10 Cost study rev C: restructure for review, numbers unchanged
    Same findings as rev B, reorganised so a reviewer can act on it. Filename
    settles at RescueSwarm_Cost_Study.xlsx; rev A (RescueSwarm_BOM_Budget.xlsx,
    whose 76,500 saving figure was wrong) is deleted.
    Seven tabs, conclusion first:
    00 Summary one printable page -- question, answer, headline table,
    five recommendations, reading guide, approval block
    01 Findings five findings as evidence -> what it means -> action
    02 Cost Summary roll-up with savings and under-pricing separated
    03 Air Vehicle 49 lines, per-line status KEEP/SUBSTITUTE/REPRICE/SOURCE
    04 Market Evidence every part with mod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
    [RescueSwarm_BOM_Budget.xlsx, RescueSwarm_Cost_Study.xlsx]
2026-08-10 Delete superseded cost-study rev B; restore Excel's cached values in the India BOM
    rev B is fully superseded by RescueSwarm_Cost_Study.xlsx (rev C). Only one cost
    study should exist -- the failure mode this repo tracks is a stale artifact
    sitting next to the live one.
    The India BOM change is not an edit: opening it in Excel repopulated the cached
    formula values that openpyxl discards on save. The CHANGELOG's 2026-08-08 entry
    flags exactly this -- anything reading with data_only=True saw None until the
    workbook was opened once. It now reads real numbers.
    Verified unchanged by it: 499 formulas, columns P/Q and their 23 hyperlinks
    intact, 01!I61/K61/L61 still SUM to row 60, and cost_model.py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
    [RescueSwarm_BOM_India.xlsx, RescueSwarm_Cost_Study_revB.xlsx]
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2026-08-17 Generate the cost study instead of maintaining it
    The workbook had drifted until it disagreed with the funding proposal about the
    headline number: it claimed a floor of 1.83 L at 52% Indian content while the
    proposal had settled on 1,57,800 at 36%. Two artifacts stating different costs
    for the same aircraft is the defect HANDOFF section 5 exists to prevent, and
    patching one of them would only have reset the clock.
    build_cost_study.py now produces the workbook by IMPORTING every figure from
    docs/proposal/figures/competition_budget.py -- the same module the proposal's
    budget section and its charts derive from. Nothing is restated in two places,
    so the two cannot disagree again.
    per aircraf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
    [RescueSwarm_Cost_Study.xlsx]
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2026-08-17 Per-line tax audit: the ask falls 10.12 L -> 8.24 L, no capability changed
    The disclosure added last commit said a per-line audit could only move the
    figure down, and that I had not done it. Done now.
    The budget grossed up the whole subtotal by 22% duty and 18% GST. Correct for
    the original ex-works estimates; wrong once market verification replaced most
    of them with INDIAN RETAIL LISTINGS, which are duty-paid and tax-paid at the
    till. The Agam board is quoted by its own manufacturer as "42,000 WITH 5% GST".
    Grossing up a gross figure counts the same tax twice.
    Every line is now classified in competition_budget.py and tax applies only to
    what is genuinely untaxed:
    tax-inclusive retail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
    [RescueSwarm_Cost_Study.xlsx]
2026-08-17 Audit every exhibit against the adopted build; drop two that duplicated others
    Checked all ten tables and twelve figures against competition_budget.py rather
    than against each other. Four were wrong, and two were redundant.
    TABLE VI DID NOT ADD UP. Two group rows were stale: air vehicle 4.83 -> 4.84 and
    ground segment 0.74 -> 0.69. As written the rows summed to 6.57 against a stated
    6.53 subtotal, which is the kind of arithmetic a finance office checks first.
    THE VEGA CO-PROCESSOR WAS CLAIMED TWICE AND WAS NOT IN THE BOM. Table IX listed
    "Indian RISC-V development kit" and Section VIII called it "a genuine
    demonstration of Indian silicon in flight" -- but the adopted aircraft did not
    carry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
    [RescueSwarm_Cost_Study.xlsx]
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2026-08-18 Real branding on the replay; BOM artefacts brought current and de-trapped
    BRANDING. The replay now uses the supplied drikr-logo.png and nidar-logo.png
    instead of my text approximations, plus the mockup's tab row (FLIGHT DATA
    active, DIAGNOSTICS and SETTINGS dimmed). Both assets are black ink on opaque
    white and the dashboard is dark, so they are inverted and keyed to alpha rather
    than pasted: paper -> transparent, ink -> opaque white, and the NIDAR
    strapline's mid-greys -> partially transparent, which reproduces the dimmer
    subtitle without a second asset. Missing assets degrade to a clean run rather
    than a crash. My "SITL replay" subtitle is gone -- it sat cramped under the tab
    box and is no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
    [RescueSwarm_BOM.xlsx, RescueSwarm_BOM_India.xlsx, RescueSwarm_BOM_India_Verified.xlsx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]
2026-08-18 Re-fly at SIM_SPEEDUP 1: NAV_DELAY vindicated, a real breach found and fixed
    Flew the mission again in SITL at speedup 1 rather than re-rendering the old
    recording a third time. It settled one open question and exposed a defect the
    old recording had been hiding.
    NAV_DELAY WORKS. The stagger is served: lift-off at 0 / 15.5 / 31.7 s against
    a commanded 0 / 15 / 30, the residual being climb time to 2 m. The committed
    recording showed 0 / 3.5 / 10.0 and docs/proposal/README.md carried it as an
    open defect. It was a speedup-3 sampling artifact, exactly as the harness's own
    comment predicted. The launch deconfliction mechanism does what the proposal
    claims. The 453.9 s clock jump does not reprodu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
    [rescueswarm-drone1.parm, rescueswarm-drone2.parm, rescueswarm-drone3.parm]
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2026-08-18 Add the companion computer the BOM was missing: 7.38 L -> 7.65 L
    Explaining the compute architecture surfaced that the bill of materials buys a
    camera and a neural accelerator and NO COMPUTER TO RUN THEM.
    The "AI accelerator" line is a Raspberry Pi AI HAT+ (Hailo-8). Raspberry Pi's
    own documentation: it "communicates using Raspberry Pi 5's PCIe Gen 3
    interface". Without a Pi 5 it is an M.2 card with nothing to plug into. The
    camera is an Arducam CSI module with nothing to connect to. And there is no
    Linux to boot, while implementation-plan.md 2.2 is built around a companion
    computer, the sizing budget allows 75 s for "Linux + ROS 2 + model load", and
    the frame constraints carry a thermal al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
    [RescueSwarm_Cost_Study.xlsx]
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2026-08-21 Correct the outstanding defects, and the one upstream cause behind most of them
    ROOT CAUSE. rescueswarm_sizing_model.py hardcoded the camera as 7.4 x 5.6 mm
    -- a 1/1.8" sensor on a 1.82 um pitch that this programme does not buy. The
    BOM buys an IMX477: type 1/2.3, 1.55 um, the same pixel COUNT on a smaller
    pixel. Every field of view, GSD, transect count and angular-blur figure
    downstream was computed for the wrong part, which is where the proposal's
    93 px, the 15 deg/s capture gate and sizing 8 all came from. The block now
    derives the sensor from its pitch, so the substitution cannot be made
    silently again. Consequences, all real: HFOV 63.3 -> 55.3 deg, GSD at 60 m
    1.82 -> 1.55 cm/px, person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
    [rescueswarm-drone1.parm, rescueswarm-drone2.parm, rescueswarm-drone3.parm]
2026-08-21 Regenerate the funding workbook, and clear the last stale totals
    The workbook was locked by Excel on the previous attempt. Regenerated: ask
    734,379, per-aircraft 156,800 (was 165,800), and the tightened specs are in
    the cells -- the accelerator now reads "REQUIREMENT IS THROUGHPUT, NOT TOPS:
    >=37 inferences/s at 640x640", the GNSS line demands an RTK FIXED solution at
    <=3 cm CEP rather than naming a product, and the camera line says FIXED FOCUS.
    Then swept for figures the reprice left behind, which found three:
    - docs/proposal/tracks/README.md still tabled the old split. Track D was
    1,07,295 and is 76,245; the total was 7,65,429 and is 7,34,379. Added a
    note saying the table is g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
    [RescueSwarm_University_Funding_Request.xlsx]
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2026-08-22 Brief: fix the propeller line rather than confess it, and expand the parts case
    Two things.
    FIXED, NOT CONFESSED. The brief carried a paragraph admitting propellers were
    under-budgeted at 1,000 each against a verified 3,250 per pair. That paragraph
    is gone because the BOM line is now 1,625, which is the real price. Ask moves
    7,34,379 -> 7,43,004. Same treatment for the other self-critical passages: if
    a number was wrong it has been corrected at source, and the document states
    the design rather than its edit history. Nothing in the brief now says we made
    a mistake, because nothing in it is still wrong.
    RESOURCES EXPANDED. Every part is now a named model at a current Indian price
    with the nu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
    [RescueSwarm_University_Funding_Request.xlsx]
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2026-08-24 Check the Tarot TL96020 datasheet against the design; three findings
    Prop adapters were specified as 6 mm bore. The TL96020 shaft is 4 mm, so
    they would not have fitted. Corrected in the BOM and the brief. This is the
    kind of thing a datasheet catches and a price list does not.
    Peak current is above the motor's continuous rating. The datasheet gives
    26.5 A max continuous. Hover draws 10.6 A per motor -- 40 %, comfortable.
    The peak at T/W 2.0 is 28.7 A, or 108 %. That is defensible, because T/W 2.0
    is a transient authority reserve and the aircraft hovers at half throttle,
    but it is the tightest margin in the propulsion chain and Section V now says
    so rather than leaving it for a reviewer to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
    [RescueSwarm_BOM.csv]
2026-08-25 Price the GNSS at the supplier quotation; the X5 is out on cost
    Teravolt quoted 2026-08-25: AeroNav-Pro RTK Rs 25,000/unit, AeroNav-X5
    Rs 1,50,000/unit, both build-to-order on 3-4 weeks.
    The X5 is rejected on price and Section IV-C now says so rather than
    leaving it under evaluation. Four units would be Rs 6,00,000 -- 80 % of the
    present programme -- and the programme total would go to Rs 15.6 lakh. It
    buys 0.6 cm + 0.5 ppm against 1 cm + 1 ppm, a four-millimetre improvement
    in a term the error budget does not turn on.
    The Pro RTK at Rs 25,000 closes the standing warning on that line: the part
    is a true RTK receiver at 0.01 m + 1 ppm CEP with native NavIC, not the
    SBAS-corrected unit the l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
    [RescueSwarm_BOM.csv]
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2026-09-02 The 40 m sweep does not clear urban buildings, and cannot be raised
    Section IV-K claimed flood-zone structures are "typically two to four storeys,
    six to twelve metres". That is true of a rural flood plain and false of the
    flooding this system is aimed at: Chennai and Mumbai contain a great deal of
    building well above 40 m, and the sweep altitude is below all of it.
    The important part is that climbing is not available. The survey altitude is
    pinned by detection, not chosen: a person in water is 1498 px2 at 40 m and
    clears the COCO small-object floor, and 959 px2 at 50 m and does not. No
    altitude both clears a 60 m building and resolves a 0.4 m target with this
    camera. Every obstacle taller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
    [20x20-ESC-Flashing.kicad_pcb, 20x20-ESC-Flashing.kicad_sch, 20x20-ESC-QC.kicad_pcb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]
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2026-09-04 Restructure the handoff, and fix a safety revert it was hiding
    Asked to improve HANDOFF.md. Verifying its claims against the repository
    turned up a reverted safety fix, so this is both edits.
    THE REVERT. RTL_LOIT_TIME sequences the descents onto the shared 3.66 m pad.
    bcf3127 measured the descent at 53 s in a SIM_SPEEDUP 1 re-fly, found that the
    20 s stagger let two aircraft close to 3.10 m against a 5 m minimum, and fixed
    it to 0/60/120 s -- by hand, in the GENERATED .parm files, without touching
    params.py. 5a1ab73 then regenerated them for an unrelated fix and put the
    breach back, in a diff that looked like routine regeneration. test_params.py
    asserted the reverted literal, so the suite s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
    [rescueswarm-drone2.parm, rescueswarm-drone3.parm]
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2026-09-04 DrikrAIO: the power block the sub-sheets came without
    The 25 ERC errors were one missing block. OpenESC-30x30 keeps its battery
    entry, shunts, current sense and both regulators on its ROOT sheet alongside
    the four channel sheets, so copying ESC.kicad_sch brought the power stages
    across with nothing to power them.
    esc_power.kicad_sch lifts that root, drops only the four channel sheets, and
    puts a hierarchical label on each pin they vacated so the existing routing
    carries up to our root instead of dangling.
    U3 STAYS, AND THAT IS THE POINT. An earlier pass deleted it as "OpenESC's board
    outline". It is not an outline -- it is the ESC's entire pad set: VBAT, BATGND,
    CUR, M1-M4 and the twelve m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
    [DrikrAIO.kicad_sch, ESC.kicad_sch, blackbox.kicad_sch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]
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
